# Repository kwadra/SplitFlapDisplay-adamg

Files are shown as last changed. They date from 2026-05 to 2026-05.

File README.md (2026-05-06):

# Split-Flap Display

A modular, 3D-printed split-flap display controllable over RS485 from a Raspberry Pi. Each module holds 64 characters and modules can be chained together to build a display of any width.

**YouTube Build Video:** https://www.youtube.com/watch?v=-C8_AtxEEQc

---

## How It Works

Each module contains:
- A 3D-printed drum that holds 64 individual flaps (one per character)
- A stepper motor driving the drum through a gear train
- A Hall effect sensor for homing
- A custom driver PCB (ATtiny1616 + RS485 transceiver + ULN2003 stepper driver)

Modules communicate over a shared RS485 bus. A Raspberry Pi running a Python web interface sends commands over USB-RS485 to each module individually by address.

---

## Repository Structure

```
cad/                       - 3D printable parts (Bambu Lab profiles included)
flaps-generator/           - OpenSCAD code to automatically generate (custom) flaps
pcb/
  driver-v2/               - Driver PCB KiCad project used in the video build
  driver-v3/               - Updated driver PCB KiCad project, slightly cheaper to manufacture
  bus-board/               - Bus board KiCad project
  bus-board-5-module/      - 5-module variant of the bus board
firmware/                  - Arduino firmware for the PCBs
frontend/                  - Raspberry Pi Python web frontend
docs/datasheets/           - Component datasheets
BOM.md                     - Bill of materials
```

**OnShape Model:** https://cad.onshape.com/documents/87c916b33ca5d6492b457485/w/b3e5f0f05f6619e6e7931347/e/582ef2164e20b0aa994708ab

---

## Parts List

See [BOM.md](BOM.md) for the complete bill of materials, broken into three sections:

- **PCB / Electronics** — all SMD components with JLCPCB part numbers for easy ordering
- **Module BOM** — 3D printed parts and hardware per module, with quantities scaled to 45 modules
- **Other Components** — system-level parts (Raspberry Pi, power supply, C14 connector, etc.)

---

## Ordering the PCB from JLCPCB

The driver board is designed to be ordered from JLCPCB with their PCB Assembly (PCBA) service so the SMD components arrive pre-soldered.

### Step 1 — Export Gerbers from KiCad

1. Open the project in `pcb/driver-v2/`
2. In KiCad PCB editor, go to **File → Fabrication Outputs → Gerbers**
3. Export to a folder, then zip the contents
4. Also export the drill file from the same menu

Alternatively, pre-exported Gerber and PCBA files are already be present in the KiCad project folder.

### Step 2 — Upload to JLCPCB

1. Go to [jlcpcb.com](https://jlcpcb.com) and click **Order Now**
2. Upload the Gerber zip file
3. Set your desired quantity (minimum 5)
4. Leave most settings at default; adjust PCB colour if desired

### Step 3 — Enable PCB Assembly (PCBA)

1. Toggle **PCB Assembly** on
2. Select **Standard PCBA** and set the assembly side to **Top Side**
3. Click **Confirm**

### Step 4 — Upload BOM and CPL Files

1. Upload the **BOM file** from the KiCad project folder — this maps component values to JLCPCB part numbers. The part numbers in `BOM.md` match what is in this file.
2. Upload the **CPL (Component Placement List)** file — this tells JLCPCB where each component sits on the board
3. Review the component matches on the next screen. All parts should auto-match using the C-numbers in [BOM.md](BOM.md). Confirm any that need manual review.

### Step 5 — Review and Order

1. Check the parts list — confirm quantities and part numbers match the [BOM.md](BOM.md) PCB section
2. Proceed through the review screens and place your order

> **Note:** A few through-hole parts (pin headers, JST connectors) are not included in PCBA. These are listed in the BOM and will need to be soldered by hand.

---

## 3D Printing

All printable files are in the `cad/` folder. A Bambu Lab print profile is included in `cad/64FlapsWithLetters (parts and bambu print profile)/` for the flaps. Print the flaps in the correct colour for each character — see the video for details on the full 64-character set.

Parts per module:
- Enclosure Body, Right Cover, Left Cover
- Drum Body, Drum Cap
- Motor Gear, Center Gear, Gear Plate
- DIN Rail Mount, Wire Retainer
- 64 Flaps

### Creating your own flaps

If you want to generate your own flaps, with your own font, size and characters, you can use the OpenSCAD script to automatically generate this.

---

## Firmware

Located in `firmware/`. The firmware is Arduino-based and targets the ATtiny1616.

- Flash via UPDI programmer (see https://github.com/SpenceKonde/AVR-Guidance/blob/master/UPDI/jtag2updi.md if you need to make one)
- Each module needs a unique address (0–44) stored in EEPROM. Be sure to edit this between flashes.

---

## Frontend

Located in `frontend/`. A Python web interface running on a Raspberry Pi sends display commands over USB-RS485 at 115200 baud.

Need a USB-serial dongle. I used this one: https://www.adafruit.com/product/5994

---

## License

This project is licensed under [Creative Commons Attribution-NonCommercial-ShareAlike 4.0 International (CC BY-NC-SA 4.0)](https://creativecommons.org/licenses/by-nc-sa/4.0/).

You are free to share and adapt this project for non-commercial purposes, as long as you give appropriate credit to Adam G Makes and distribute any derivatives under the same license.

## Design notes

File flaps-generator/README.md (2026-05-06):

# Flaps generator (`flaps.scad`)

## OpenSCAD (brief)

[OpenSCAD](https://openscad.org/) is a script-based 3D CAD tool: you describe models as code (extrusions, booleans, imports), adjust parameters, then preview or fully render solid geometry and export meshes (e.g. STL). There is no interactive mesh sculpting—changes are edits to the `.scad` file.

## What `flaps.scad` does

The script builds a grid of split-flap blanks matching the outline in `flap.dxf`. For each flap it uses **three adjacent characters** from your sequence (previous / visible / next) so the physical flap matches how letters wrap on a drum.

You control:

- **`font`** — font family and style (OpenSCAD font string, e.g. `Consolas:style=Regular`)
- **`fontsize`** — base letter height passed to OpenSCAD `text()` on each flap face
- **`chars`** — exactly **64 characters** in order; index `0…63` maps to the printed sheet (the loops stop before character index 64)
- **`charSizeOffset`** — Per character adjustment of the size. For example '@' can be make smaller.
- **`charYposOffset`** — Allows X position adjustment per character. The default is to align in the center. But characters like `'` need to be on the top

At the top of `flaps.scad`, `MakeFlaps(1)` produces the flap bodies with letter cutouts; `MakeFlaps(2)` produces only the thin letter inlays for multi-material printing.

## How to use

1. Set **`font`**, **`fontsize`**, **`chars`** (64 characters), and optionally **`charSizeOffset`** / **`charYposOffset`** (each 64 entries, aligned by index with **`chars`**) as needed.
2. **Flap bodies:** Comment out `MakeFlaps(2);` and keep **`MakeFlaps(1);`** active. Run a **full render** (OpenSCAD: **F6**), then **Export → Export as STL**.
3. **Letter inlays:** Comment out `MakeFlaps(1);` and keep **`MakeFlaps(2);`** active. Full render again (**F6**), export a second STL.

   *(Preview-only **F5** is not enough for a clean STL export; always use full render for exports.)*

4. **Bambu Studio:** Import **both** STL files. When prompted, choose **import as a single object** (so both parts stay aligned as one assembly).
5. In the object/plate list, assign **Filament 1** and **Filament 2** to the two bodies so the slicer maps each STL to the correct filament.

Example in Bambu Studio (Preview): one grouped object with body + inlay STLs, each mapped to a filament slot.

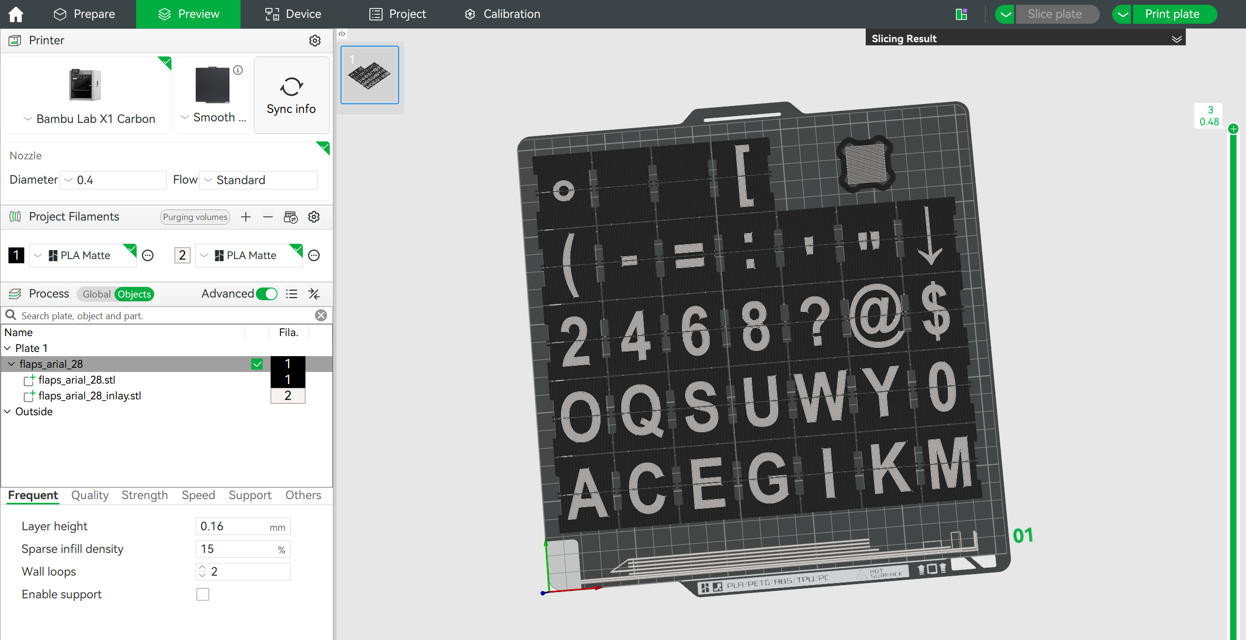
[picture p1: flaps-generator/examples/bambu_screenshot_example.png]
Bambu Studio: grouped flap body and inlay STLs with Filament 1 / Filament 2


License for this generator: see comments in `flaps.scad` (Creative Commons BY-NC-SA 4.0).

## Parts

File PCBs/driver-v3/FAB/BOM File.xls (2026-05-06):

Comment | Designator | Footprint | JLCPCB Part #
ATtiny1616-MNR | U1 | VQFN-20-1EP_3x3mm_P0.4mm_EP1.7x1.7mm | C507118
470n | C3,C8,C6,C2 | C_0603_1608Metric | C1623
ULN2003ADR | U2 | SOIC-16W_5.3x10.2mm_P1.27mm | C7512
HallEffect | J4 | PinHeader_1x03_P2.54mm_Vertical | C131339
100u | C1 | C_Elec_5x5.4 | C3347
100n | C7 | C_0603_1608Metric | C14663
0R | R1 | R_0805_2012Metric | C17477
LED | D1 | LED_0201_0603Metric | C2286
StepperConnector | J3 | JST_XH_B5B-XH-A_1x05_P2.50mm_Vertical | C157991
SN65HVD72DR | U3 | SOIC-8_5.3x6.2mm_P1.27mm | C48125
60R | R2 | R_0201_0603Metric | C166918
SPX3819M5-L-3-3 | U5 | SOT-23-5 | C20617301
SPX3819M5-L-5-0 | U6 | SOT-23-5 | C20617302
10u | C5,C9,C4 | C_0603_1608Metric | C19702

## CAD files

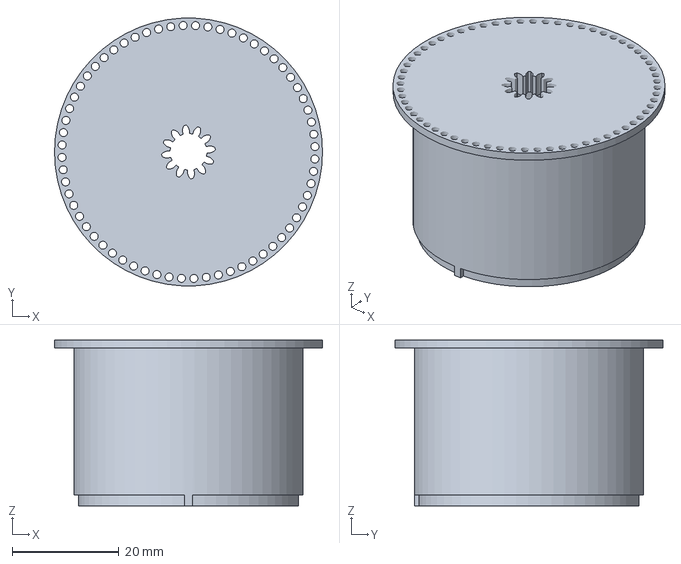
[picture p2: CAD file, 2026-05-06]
CAD Files/Character Drum - Character Drum Main.3mf
50.3 x 50.2 x 31.1 mm

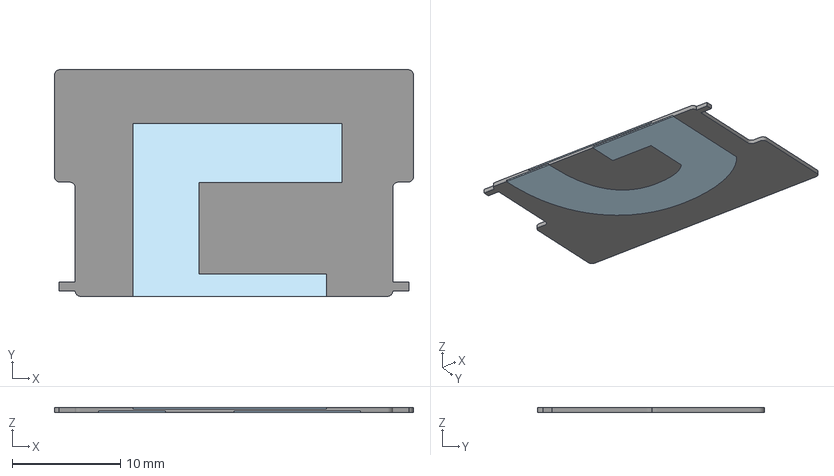
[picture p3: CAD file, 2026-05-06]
CAD Files/64FlapsWithLetters (parts and bambu print profile)/Flap7.3mf
33.1 x 20.9 x 0.48 mm
G_Bottom
Flap7
F_Top

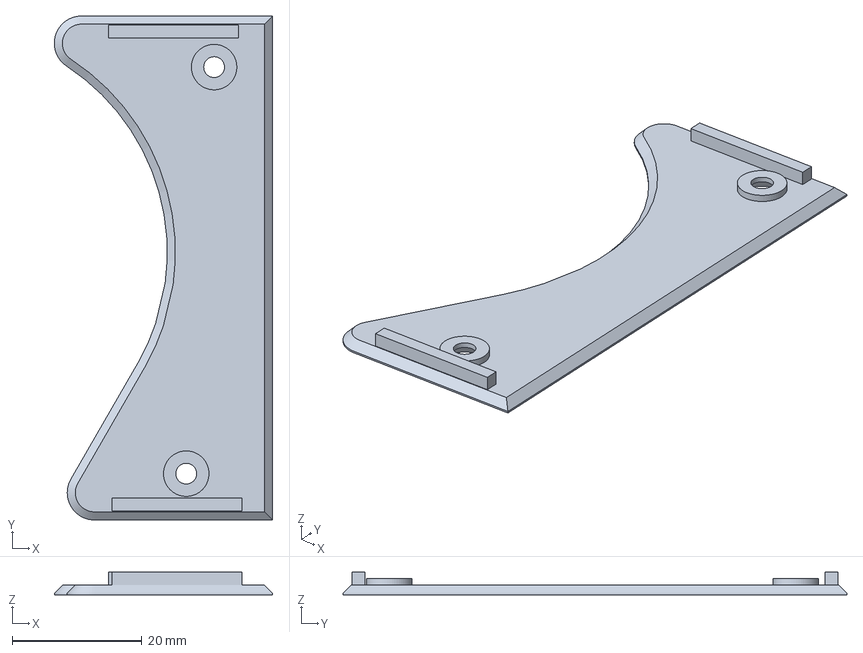
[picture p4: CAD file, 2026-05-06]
CAD Files/Module Enclosure - Enclosure Cover Bottom.3mf
33.6 x 77.6 x 3.50 mm

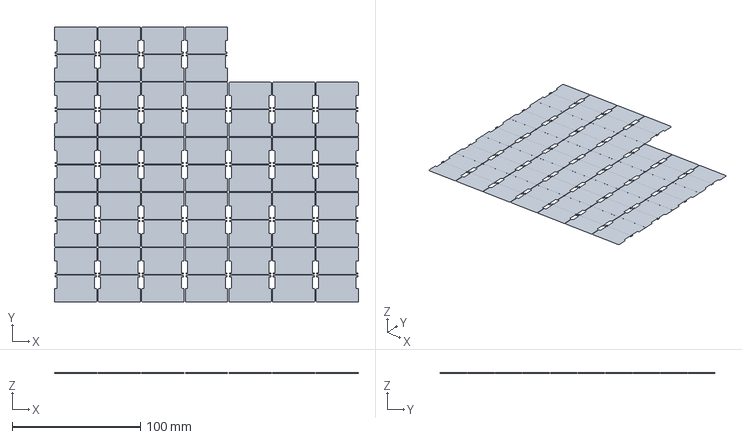
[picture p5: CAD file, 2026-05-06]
flaps-generator/examples/flaps_arial_28.3mf
237.1 x 214.3 x 0.48 mm

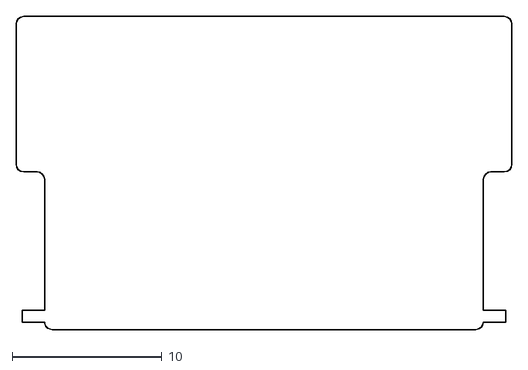
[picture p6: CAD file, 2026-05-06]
flaps-generator/flap.dxf
33.1 x 20.9

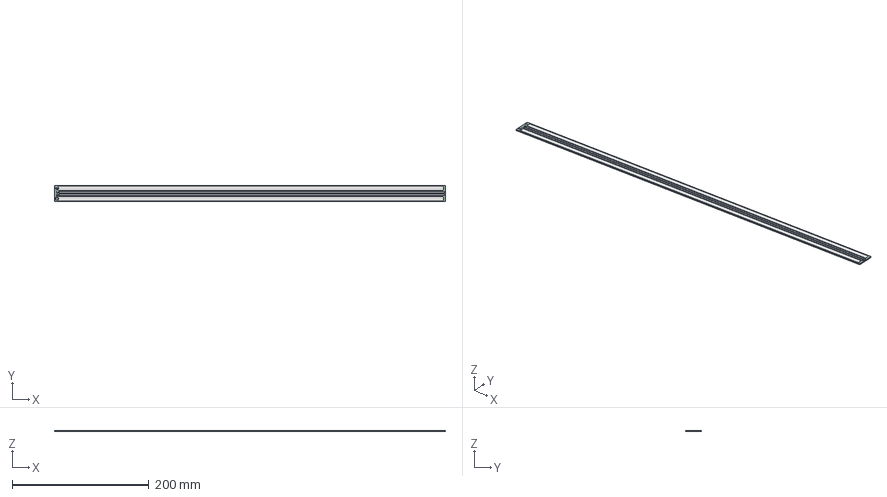
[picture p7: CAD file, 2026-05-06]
PCBs/bus-board/SplitFlapBusBoard.step
572.6 x 24.0 x 1.62 mm
SplitFlapBusBoard_pad
SplitFlapBusBoard_silkscreen
SplitFlapBusBoard_PCB

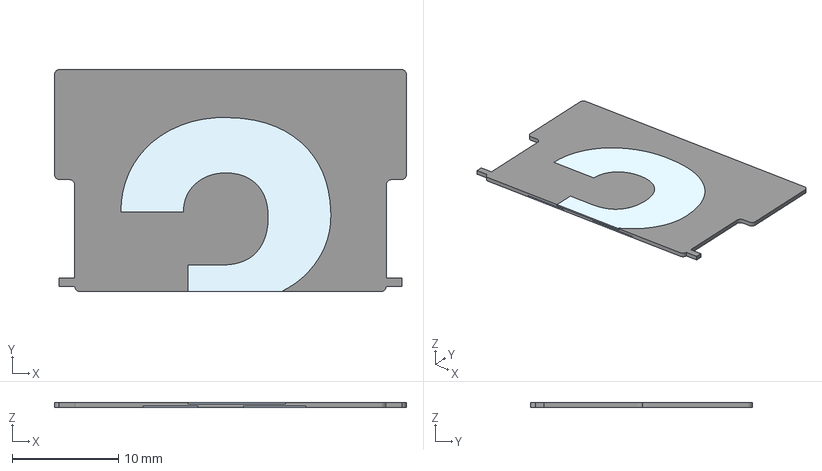
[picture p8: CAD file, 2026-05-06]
CAD Files/64FlapsWithLetters (parts and bambu print profile)/Flap31.3mf
33.1 x 20.9 x 0.48 mm
4_Bottom
Flap31
3_Top

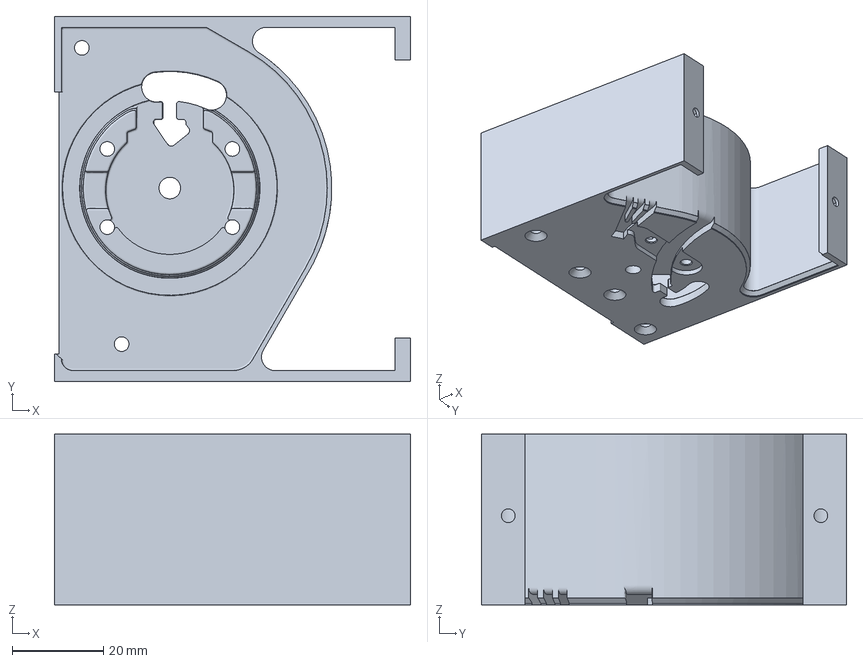
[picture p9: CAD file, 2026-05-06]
CAD Files/Module Enclosure - Enclosure.3mf
78.0 x 80.0 x 37.4 mm

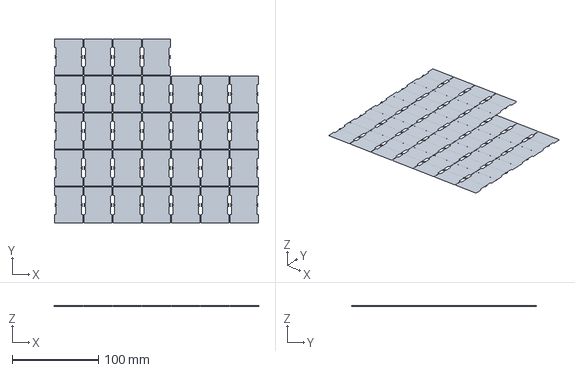
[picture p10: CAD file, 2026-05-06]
flaps-generator/examples/flaps_consolas_28.3mf
237.1 x 214.3 x 0.48 mm

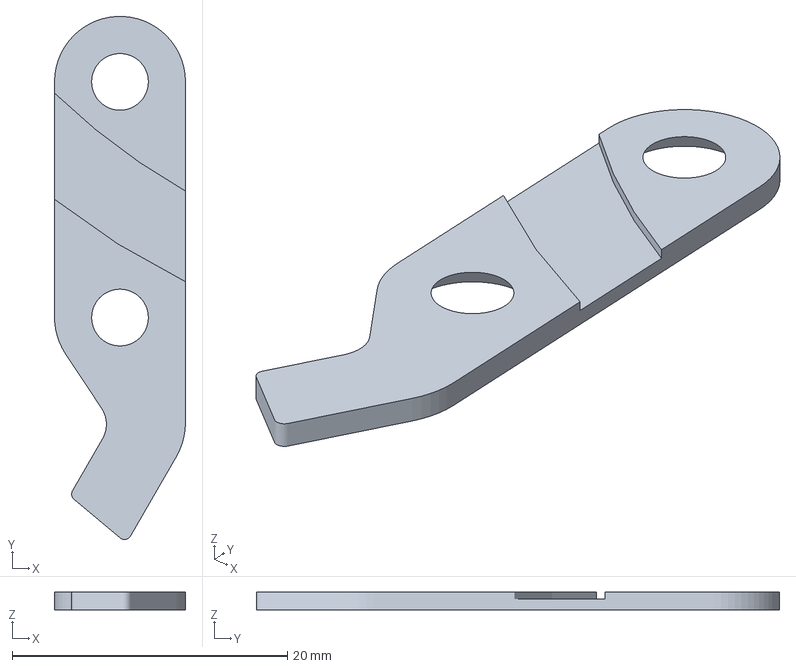
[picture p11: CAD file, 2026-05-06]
CAD Files/Wire Retainer.3mf
9.52 x 38.0 x 1.30 mm

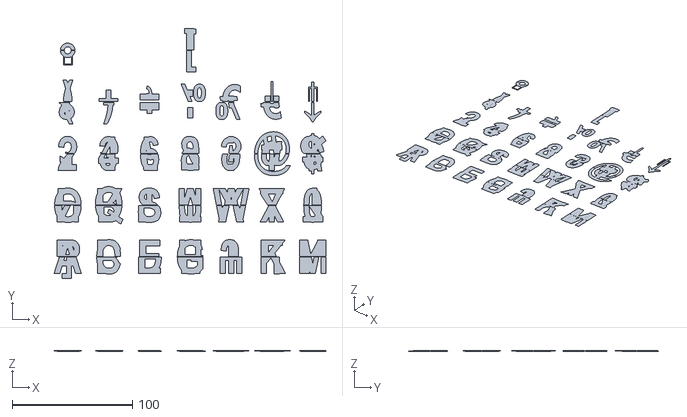
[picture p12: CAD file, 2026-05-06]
flaps-generator/examples/flaps_arial_28_inlay.stl
226.5 x 207.9 x 0.48

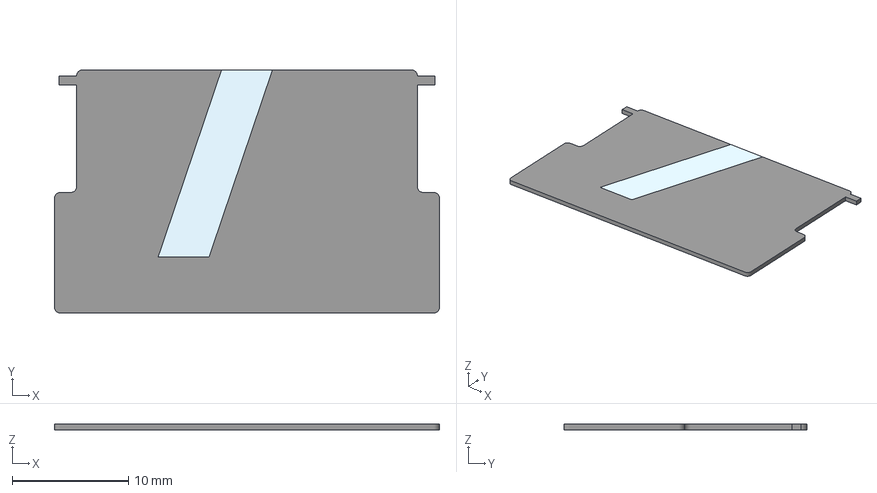
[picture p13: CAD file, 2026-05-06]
CAD Files/64FlapsWithLetters (parts and bambu print profile)/Flap54.3mf
33.1 x 20.9 x 0.48 mm
Flap54
Slash_Bottom

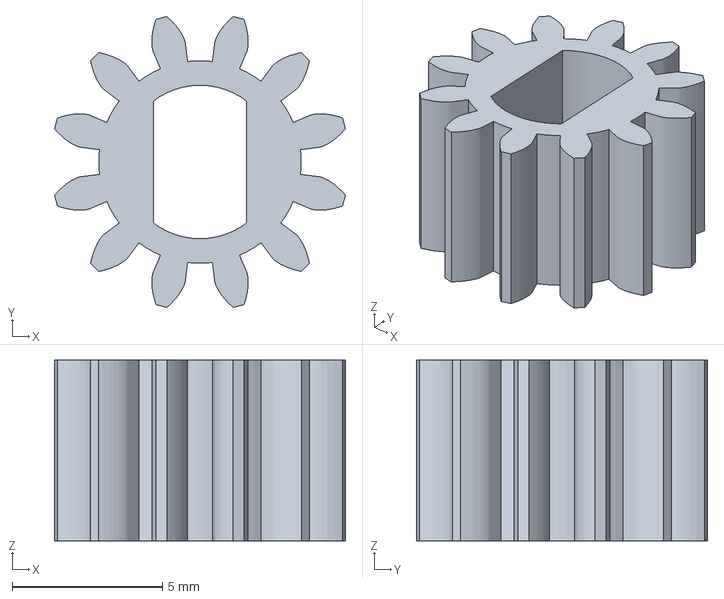
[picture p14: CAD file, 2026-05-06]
CAD Files/Motor Gear.3mf
9.67 x 9.67 x 6.00 mm

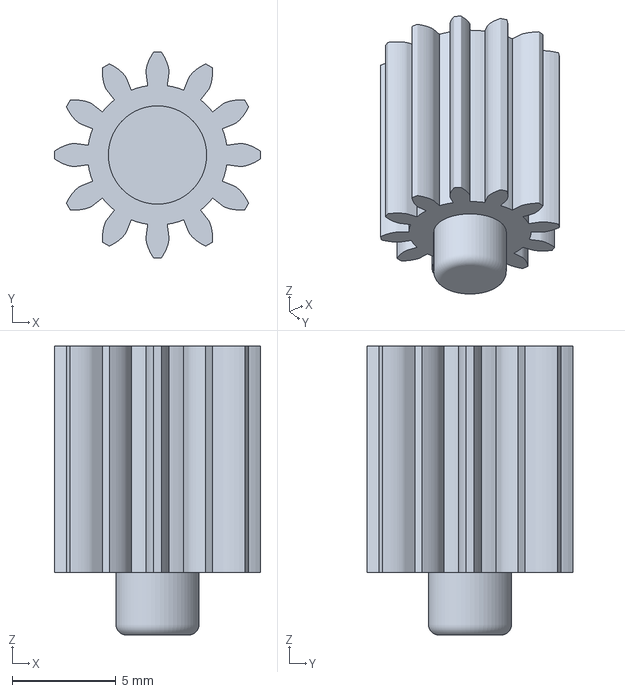
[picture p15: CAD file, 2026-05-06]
CAD Files/Center Gear.3mf
9.91 x 9.91 x 13.9 mm

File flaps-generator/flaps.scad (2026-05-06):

// Flap Generator for splitflap design based on: https://github.com/adamgmakes/SplitFlapDisplay
//
// Flap generator created by Richard Garsthagen (the.anykey@gmail.com)
// License under creative commons: https://creativecommons.org/licenses/by-nc-sa/4.0/

$fn=180; // Quality of render
layers = 3;
layerheight = 0.16;
font = "Consolas:style=bold";
fontsize = 28;

chars = "ABCDEFGHIJKLMNOPQRSTUVWXYZ0123456789?!@#$&()-+=;:%'\u20AC\"\u2191\u2193\u20BF\u00b0\u263A_   []";
charSizeOffset = [0,0,0,0,0,0,0,0,0,0,0,0,0,0,0,0,0,0,0,0,0,0,0,0,0,0,0,0,0,0,0,0,0,0,0,0,0,0,-4,0,0,0,0,0,0,0,0,0,0,0,0,0,0,0,0,0,0,0,0,0,0,0,0,0];
charYposOffset = [0,0,0,0,0,0,0,0,0,0,0,0,0,0,0,0,0,0,0,0,0,0,0,0,0,0,0,0,0,0,0,0,0,0,0,0,0,0,0,0,0,0,0,0,0,0,0,0,0,0,9,0,9,0,0,0,9,0,-12,0,0,0,0,0];


// Make the flaps 
MakeFlaps(1);

// Make the letter inlays
MakeFlaps(2);

module MakeFlaps(part){
    for ( y = [0 : 5] ){
        for ( x = [0 : 2 : 12] ){
            char = (y*14)+x;
            if (char<64) {
                if (char==0){
                 translate([17+(x*17),22+(y*43),0])
                 flap(63, char, char+1, part); }
                else if (char==63) {
                 translate([17+(x*17),22+(y*43),0])
                 flap(char-1, char, 0, part); }
                else {
                 translate([17+(x*17),22+(y*43),0])
                 flap(char-1, char, char+1, part);} 
            }
        }
    }
}

module flap(c1,c2,c3, part){
    //print flaps with character cutout
    if (part==1){
     difference(){ 
     union(){
     color("black")
     linear_extrude(h=(layers*layerheight))
     import("flap.dxf");
     
     color("black")
     linear_extrude(h=(layers*layerheight))
     rotate([0,0,180])
     import("flap.dxf");
     }
     char1(c1);
     char2(c2);
     char3(c3);
     }
    }

    //print just the characters
    if (part==2){
     char1(c1);
     char2(c2);
     char3(c3);
    }
}

module char1(c){
 difference(){
     color("white")
     translate([0,-charYposOffset[c],0])
     linear_extrude(h=layerheight)
     rotate([180,0,0])
     text(chars[c], size=fontsize+charSizeOffset[c], font=font, halign="center", valign="center");
     
     translate([-20,-0.25,0])
     cube([50,20,layerheight]);
 }
}

module char2(c){
difference(){
     color("white")
     translate([0,charYposOffset[c],layerheight*(layers-1)])
     linear_extrude(h=layerheight)
     text(chars[c], size=fontsize+charSizeOffset[c], font=font, halign="center", valign="center");
     
     translate([-20,-0.25,layerheight*(layers-1)])
     cube([50,0.5,layerheight]);
     
}
}

module char3(c){
 difference(){
     color("white")
     translate([0,-charYposOffset[c],0])
     linear_extrude(h=layerheight)
     rotate([180,0,0])
     text(chars[c], size=fontsize+charSizeOffset[c], font=font, halign="center", valign="center");
     
     translate([-20,-20+0.25,0])
     cube([50,20,layerheight]);
 }
}

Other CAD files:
CAD Files/64FlapsWithLetters (parts and bambu print profile)/Flap12.3mf
CAD Files/64FlapsWithLetters (parts and bambu print profile)/Flap2.3mf
CAD Files/64FlapsWithLetters (parts and bambu print profile)/Flap17.3mf
CAD Files/64FlapsWithLetters (parts and bambu print profile)/Flap26.3mf
CAD Files/64FlapsWithLetters (parts and bambu print profile)/64FlapsPrintProfile.3mf
CAD Files/64FlapsWithLetters (parts and bambu print profile)/Flap1.3mf
CAD Files/64FlapsWithLetters (parts and bambu print profile)/Flap10.3mf
CAD Files/64FlapsWithLetters (parts and bambu print profile)/Flap11.3mf
CAD Files/64FlapsWithLetters (parts and bambu print profile)/Flap13.3mf
CAD Files/64FlapsWithLetters (parts and bambu print profile)/Flap14.3mf
CAD Files/64FlapsWithLetters (parts and bambu print profile)/Flap15.3mf
CAD Files/64FlapsWithLetters (parts and bambu print profile)/Flap16.3mf
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

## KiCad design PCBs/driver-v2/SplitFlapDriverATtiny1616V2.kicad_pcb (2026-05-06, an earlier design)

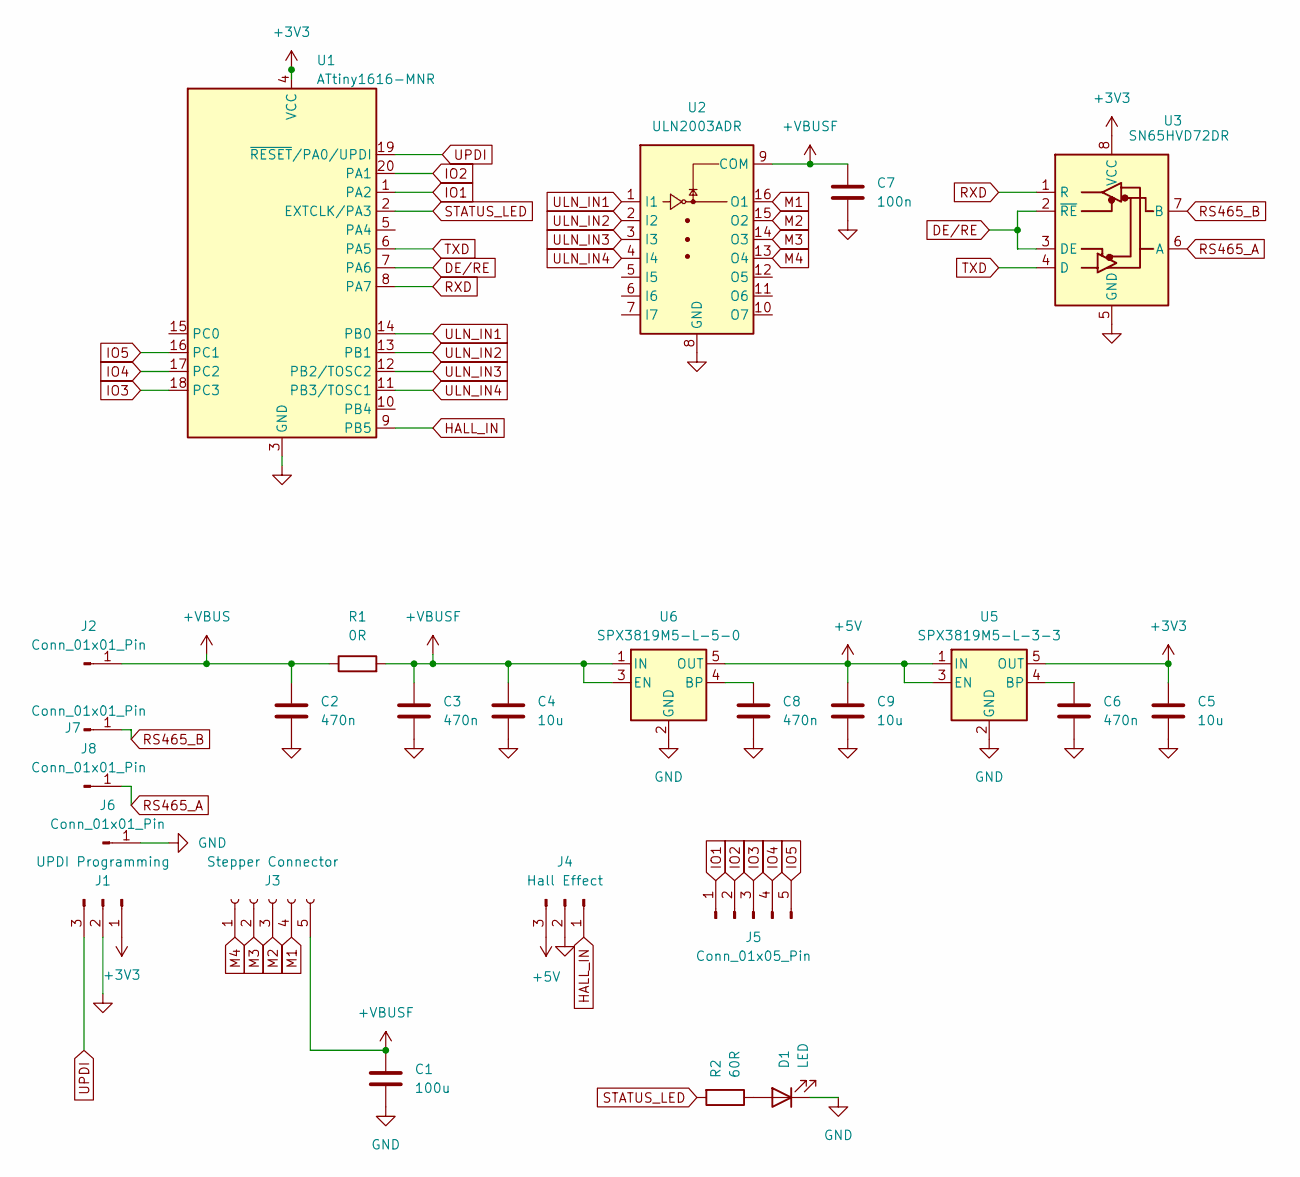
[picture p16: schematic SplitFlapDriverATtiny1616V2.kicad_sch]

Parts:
C1: 100u; C_Elec_5x5.4
C2, C3, C6, C8: 470n; C_0603_1608Metric
C4, C5, C9: 10u; C_0603_1608Metric
C7: 100n; C_0603_1608Metric
D1: LED; LED_0201_0603Metric
J1: UPDI Programming; PinHeader_1x03_P2.54mm_Vertical
J2, J6, J7, J8: Conn_01x01_Pin; PinHeader_1x01_P2.54mm_Vertical
J3: Stepper Connector; JST_XH_B5B-XH-A_1x05_P2.50mm_Vertical
J4: Hall Effect; JST_PH_B3B-PH-K_1x03_P2.00mm_Vertical
J5: Conn_01x05_Pin; PinHeader_1x05_P2.54mm_Vertical
R1: 0R; R_0805_2012Metric
R2: 60R; R_0201_0603Metric
U1: ATtiny1616-MNR; VQFN-20-1EP_3x3mm_P0.4mm_EP1.7x1.7mm; Manufacturer Part Number ATTINY1616-MNR; JLCPCB Part Number C507118
U2: ULN2003ADR; SOIC-16W_5.3x10.2mm_P1.27mm; Manufacturer Part Number ULN2003ADR; JLCPCB Part Number C7512
U3: SN65HVD72DR; SOIC-8_5.3x6.2mm_P1.27mm; Manufacturer Part Number SN65HVD72DR; JLCPCB Part Number C48125
U5: SPX3819M5-L-3-3; SOT-23-5
U6: SPX3819M5-L-5-0; SOT-23-5

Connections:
+3V3: C5.1, J1.1, U1.4 (VCC), U3.8 (VCC), U5.5 (OUT)
+5V: C9.1, J4.3, U5.1 (IN), U5.3 (EN), U6.5 (OUT)
+VBUS: C2.1, J2.1, R1.1
+VBUSF: C1.1, C3.1, C4.1, C7.1, J3.5, R1.2, U2.9 (COM), U6.1 (IN), U6.3 (EN)
DE/RE: U1.7 (PA6), U3.2 (~RE), U3.3 (DE)
GND: C1.2, C2.2, C3.2, C4.2, C5.2, C6.2, C7.2, C8.2, C9.2, D1.1 (K), J1.2, J4.2, J6.1, U1.3 (GND), U2.8 (GND), U3.5 (GND), U5.2 (GND), U6.2 (GND)
HALL_IN: J4.1, U1.9 (PB5)
IO1: J5.1, U1.1 (PA2)
IO2: J5.2, U1.20 (PA1)
IO3: J5.3, U1.18 (PC3)
IO4: J5.4, U1.17 (PC2)
IO5: J5.5, U1.16 (PC1)
M1: J3.4, U2.16 (O1)
M2: J3.3, U2.15 (O2)
M3: J3.2, U2.14 (O3)
M4: J3.1, U2.13 (O4)
unnamed: D1.2 (A), R2.1
unnamed: C6.1, U5.4 (BP)
unnamed: C8.1, U6.4 (BP)
RS465_A: J8.1, U3.6 (A)
RS465_B: J7.1, U3.7 (B)
RXD: U1.8 (PA7), U3.1 (R)
STATUS_LED: R2.2, U1.2 (EXTCLK/PA3)
TXD: U1.6 (PA5), U3.4 (D)
ULN_IN1: U1.14 (PB0), U2.1 (I1)
ULN_IN2: U1.13 (PB1), U2.2 (I2)
ULN_IN3: U1.12 (PB2/TOSC2), U2.3 (I3)
ULN_IN4: U1.11 (PB3/TOSC1), U2.4 (I4)
UPDI: J1.3, U1.19 (~RESET/PA0/UPDI)

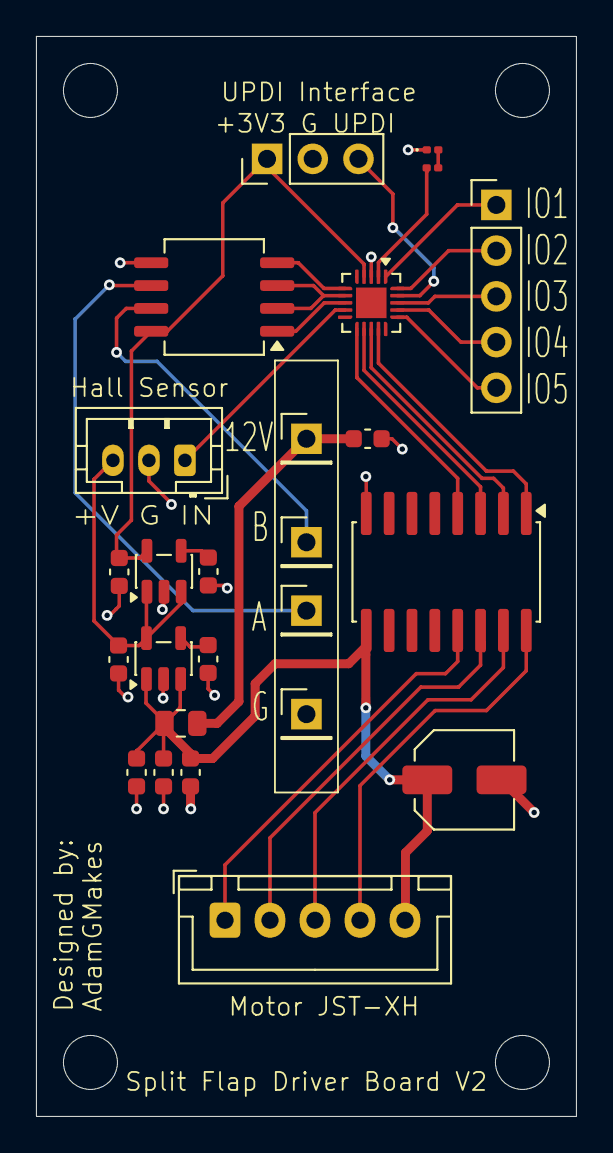
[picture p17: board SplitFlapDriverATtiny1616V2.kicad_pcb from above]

Board: 2 copper layers, 30.0 x 60.0 mm, 25 parts (0 on the bottom side), 29 nets.

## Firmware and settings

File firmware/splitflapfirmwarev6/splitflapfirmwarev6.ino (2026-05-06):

#include <SoftwareSerial.h>
#include <EEPROM.h>

// ==========================================
//               CONFIGURATION
// ==========================================
// !!! CHANGE THIS FOR EACH MODULE TODAY !!!
const uint8_t HARDCODED_ID = 38; 

const String FLAP_CHARS = " ABCDEFGHIJKLMNOPQRSTUVWXYZ0123456789!@#$&()-+=;q:%'.,/?*roygbpw";

// EEPROM MAP
const int ADDR_INIT = 0;          // 1 byte  - Initialization flag
const int ADDR_HOME_OFFSET = 1;   // 2 bytes - Offset from magnet
const int ADDR_TOTAL_STEPS = 3;   // 2 bytes - Step length of reel
const int ADDR_MODULE_ID = 5;     // 1 byte  - The Module's Assigned ID (0-44)
const int ADDR_AUTO_HOME = 6;     // 1 byte  - Toggle for booting logic
const int ADDR_SAVED_POS = 7;     // 2 bytes - Last known step position
const int ADDR_SAVED_INDEX = 9;   // 1 byte  - Last known character index
const int ADDR_MAP_START = 12;    // 128 bytes - Exact character positions
const uint8_t INIT_VALUE = 0x5D;  // Magic number updated for new map

// Operating Variables
uint8_t moduleId = 255;
char idChars[2] = {'*', '*'};
bool autoHomeEnabled = true;

int stepsFromHallToZero = 2832;
int totalStepsPerRev = 4096;

// ==========================================
//              PIN DEFINITIONS
// ==========================================
const int RS485_RX = 3;
const int RS485_TX = 1;
const int RS485_DE = 2;

#define IN1 9
#define IN2 8
#define IN3 7
#define IN4 6
#define HALL_PIN 4

// ==========================================
//               GLOBALS
// ==========================================
SoftwareSerial rs485(RS485_RX, RS485_TX);

long currentStepPos = 0; 
int currentPhase = 0;
int parseState = 0; 
int currentFlapIndex = -1;
int tempIndex = -1;

const int stepDelay = 1;
String buffer = "";
unsigned long lastSerialTime = 0;

const uint8_t halfStepSequence[8][4] = {
  {1, 0, 0, 0}, {1, 1, 0, 0}, {0, 1, 0, 0}, {0, 1, 1, 0},
  {0, 0, 1, 0}, {0, 0, 1, 1}, {0, 0, 0, 1}, {1, 0, 0, 1}
};

// ==========================================
//             EEPROM FUNCTIONS
// ==========================================

void saveHomeOffset() { EEPROM.put(ADDR_HOME_OFFSET, stepsFromHallToZero); }
void saveTotalSteps() { EEPROM.put(ADDR_TOTAL_STEPS, totalStepsPerRev); }

void saveState() {
  if (!autoHomeEnabled) {
    EEPROM.put(ADDR_SAVED_POS, currentStepPos);
    EEPROM.put(ADDR_SAVED_INDEX, currentFlapIndex);
  }
}

void updateIdChars() {
  if(moduleId < 100) {
    idChars[0] = (moduleId / 10) + '0';
    idChars[1] = (moduleId % 10) + '0';
  }
}

void dumpEeprom() {
  // CRITICAL FIX: Give the Raspberry Pi's USB dongle 50ms to switch into listening mode
  delay(50); 
  digitalWrite(RS485_DE, HIGH);
  delay(10); 
  
  rs485.print("m");
  if(moduleId < 10) rs485.print("0");
  rs485.print(moduleId);
  rs485.print("d:");
  rs485.print(stepsFromHallToZero);
  rs485.print(":");
  rs485.print(totalStepsPerRev);
  rs485.print(":");
  
  bool first = true;
  for(int i=0; i<64; i++) {
    uint16_t pos = 0xFFFF;
    EEPROM.get(ADDR_MAP_START + (i * 2), pos);
    if(pos != 0xFFFF) {
      if(!first) rs485.print(",");
      rs485.print(i);
      rs485.print("=");
      rs485.print(pos);
      first = false;
    }
  }
  
  rs485.print("\n");
  delay(100); 
  digitalWrite(RS485_DE, LOW);
}

// ==========================================
//             MOTOR FUNCTIONS
// ==========================================

void applyStep(const uint8_t *step) {
  digitalWrite(IN1, step[0]);
  digitalWrite(IN2, step[1]);
  digitalWrite(IN3, step[2]); 
  digitalWrite(IN4, step[3]);
}

void stepBackward(int steps) {
  for (int k = 0; k < steps; k++) {
    bool hallNow = hallActive();
    static bool lastHallState = false;

    if (hallNow && !lastHallState) {
      currentStepPos = totalStepsPerRev - stepsFromHallToZero;
    }
    lastHallState = hallNow;

    currentPhase--;
    if (currentPhase < 0) {
      currentPhase = 7;
    }
    
    applyStep(halfStepSequence[currentPhase]);
    delay(stepDelay);
    
    currentStepPos++;
    if (currentStepPos >= totalStepsPerRev) {
      currentStepPos = 0;
    }
  }
}

void releaseMotor() {
  digitalWrite(IN1,0); digitalWrite(IN2,0); digitalWrite(IN3,0); digitalWrite(IN4,0);
}

bool hallActive() {
  return (digitalRead(HALL_PIN) == LOW);
}

// ==========================================
//             LOGIC FUNCTIONS
// ==========================================

void homeModule() {
  long safety = 0;
  while (!hallActive() && safety < (totalStepsPerRev + 500)) {
    stepBackward(1);
    safety++;
  }
  
  stepBackward(stepsFromHallToZero);
  currentStepPos = 0; 
  currentFlapIndex = 0;
  releaseMotor();
}

void calibrateModule() {
  long safety = 0;
  while (hallActive() && safety < 4000) {
    stepBackward(1);
    safety++;
    delay(5);
  }

  safety = 0;
  while (!hallActive() && safety < 5000) {
    stepBackward(1);
    safety++;
  }

  while (hallActive()) {
    stepBackward(1);
  }

  int measuredSteps = 0;
  while (!hallActive() && measuredSteps < 5000) {
    stepBackward(1);
    measuredSteps++;
  }

  while (hallActive()) {
    stepBackward(1);
    measuredSteps++;
  }

  // CRITICAL FIX: Wait for Pi to be ready
  delay(50);
  digitalWrite(RS485_DE, HIGH);
  delay(10); 
  
  rs485.print("m");
  if(moduleId < 100) {
    rs485.print(idChars[0]);
    rs485.print(idChars[1]);
  } else {
    rs485.print("XX");
  }
  rs485.print(":");
  rs485.print(measuredSteps);
  rs485.print("\n");
  
  delay(100); 
  digitalWrite(RS485_DE, LOW);
  
  totalStepsPerRev = measuredSteps;
  saveTotalSteps();
  homeModule();
  saveState();
}

void moveToChar(char targetChar) {
  int targetIndex = FLAP_CHARS.indexOf(targetChar);
  if (targetIndex == -1) return;
  if (currentFlapIndex == targetIndex) return; 
  
  if (currentFlapIndex == -1) {
    homeModule();
  }

  uint16_t mappedPos = 0xFFFF;
  EEPROM.get(ADDR_MAP_START + (targetIndex * 2), mappedPos);
  
  long targetStepPos;
  if (mappedPos != 0xFFFF) {
    targetStepPos = mappedPos;
  } else {
    targetStepPos = ((long)targetIndex * (long)totalStepsPerRev) / 64;
  }
  
  long stepsToMove = targetStepPos - currentStepPos;
  if (stepsToMove < 0) {
    stepsToMove += totalStepsPerRev;
  }
  
  while(stepsToMove > 0) {
    stepBackward(1);
    stepsToMove--;
  }

  releaseMotor();
  currentFlapIndex = targetIndex; 
  saveState(); 
}

// ==========================================
//              MAIN LOOP
// ==========================================

void setup() {
  pinMode(IN1, OUTPUT);
  pinMode(IN2, OUTPUT);
  pinMode(IN3, OUTPUT); 
  pinMode(IN4, OUTPUT);
  pinMode(HALL_PIN, INPUT_PULLUP);
  
  pinMode(RS485_DE, OUTPUT);
  digitalWrite(RS485_DE, LOW); 
  
  if (EEPROM.read(ADDR_INIT) == INIT_VALUE) {
    EEPROM.get(ADDR_HOME_OFFSET, stepsFromHallToZero);
    EEPROM.get(ADDR_TOTAL_STEPS, totalStepsPerRev);
    moduleId = EEPROM.read(ADDR_MODULE_ID);
    autoHomeEnabled = (EEPROM.read(ADDR_AUTO_HOME) == 1);
  } else {
    EEPROM.write(ADDR_INIT, INIT_VALUE);
    saveHomeOffset();
    saveTotalSteps();
    
    moduleId = HARDCODED_ID; 
    EEPROM.write(ADDR_MODULE_ID, moduleId);
    
    EEPROM.write(ADDR_AUTO_HOME, 1);
    autoHomeEnabled = true;
    
    for(int i=0; i<64; i++) {
      uint16_t empty = 0xFFFF;
      EEPROM.put(ADDR_MAP_START + (i*2), empty);
    }
  }

  updateIdChars();
  rs485.begin(9600);

  if (moduleId != 255) {
    delay(moduleId * 150); 
  }
  
  if (autoHomeEnabled) {
    homeModule();
    saveState();
  } else {
    EEPROM.get(ADDR_SAVED_POS, currentStepPos);
    if (currentStepPos >= totalStepsPerRev) currentStepPos = 0;
    currentFlapIndex = (int8_t)EEPROM.read(ADDR_SAVED_INDEX);
  }
}

void loop() {
  while (rs485.available()) {
    char c = rs485.read();
    lastSerialTime = millis();
    
    switch (parseState) {
      case 0: if (c == 'm') parseState = 1; break;
      case 1: if (c == idChars[0] || c == '*') parseState = 2; else parseState = 0; break;
      case 2: if (c == idChars[1] || c == '*') parseState = 3; else parseState = 0; break;
      
      case 3: 
        if (c == '-') parseState = 4;
        else if (c == 'h') { homeModule(); saveState(); parseState = 0; }
        else if (c == 'c') { calibrateModule(); parseState = 0; }
        else if (c == 'o') { buffer = ""; parseState = 5; }
        else if (c == 't') { buffer = ""; parseState = 6; }
        else if (c == 's') { buffer = ""; parseState = 7; } 
        else if (c == 'g') { buffer = ""; parseState = 8; } 
        else if (c == 'w') { buffer = ""; tempIndex = -1; parseState = 9; } 
        else if (c == 'i') { buffer = ""; parseState = 10; } 
        else if (c == 'a') { buffer = ""; parseState = 11; } 
        else if (c == 'd') { dumpEeprom(); parseState = 0; } 
        else if (c == 'e') { 
          for(int i=0; i<64; i++) {
            uint16_t empty = 0xFFFF;
            EEPROM.put(ADDR_MAP_START + (i*2), empty);
          }
          parseState = 0;
        } 
        else parseState = 0;
        break;
        
      case 4: moveToChar(c); parseState = 0; break;
      
      case 5: 
        if (isDigit(c)) buffer += c;
        else { 
          if (buffer.length()>0) {
            stepsFromHallToZero = buffer.toInt(); 
            saveHomeOffset();
          }
          parseState=0; 
        }
        break;
        
      case 6: 
        if (isDigit(c)) buffer += c;
        else { 
          if (buffer.length()>0) {
            totalStepsPerRev = buffer.toInt(); 
            saveTotalSteps();
          }
          parseState=0; 
        }
        break;
        
      case 7: 
        if (isDigit(c)) buffer += c;
        else { 
          if (buffer.length()>0) {
            int stepsToMove = buffer.toInt();
            stepBackward(stepsToMove);
            releaseMotor();
            stepsFromHallToZero += stepsToMove;
            saveHomeOffset();
          }
          parseState=0; 
        }
        break;
        
      case 8: 
        if (isDigit(c)) buffer += c;
        else {
          if (buffer.length() > 0) {
            long targetStep = buffer.toInt();
            long stepsToMove = targetStep - currentStepPos;
            if (stepsToMove < 0) stepsToMove += totalStepsPerRev;
            while(stepsToMove > 0) { stepBackward(1); stepsToMove--; }
            releaseMotor();
            currentFlapIndex = -2;
            saveState(); 
          }
          parseState = 0;
        }
        break;
        
      case 9: 
        if (c == ':') {
          tempIndex = buffer.toInt();
          buffer = "";
        } else if (isDigit(c)) {
          buffer += c;
        } else {
          if (buffer.length() > 0 && tempIndex != -1) {
            uint16_t pos = buffer.toInt();
            EEPROM.put(ADDR_MAP_START + (tempIndex * 2), pos);
          }
          parseState = 0;
        }
        break;

      case 10: 
        if (isDigit(c)) buffer += c;
        else {
          if (buffer.length() > 0) {
            moduleId = buffer.toInt();
            EEPROM.write(ADDR_MODULE_ID, moduleId);
            updateIdChars();
          }
          parseState = 0;
        }
        break;

      case 11: 
        if (isDigit(c)) buffer += c;
        else {
          if (buffer.length() > 0) {
            autoHomeEnabled = (buffer.toInt() == 1);
            EEPROM.write(ADDR_AUTO_HOME, autoHomeEnabled ? 1 : 0);
            saveState();
          }
          parseState = 0;
        }
        break;
    }
  }

  if ((parseState >= 5 && parseState <= 11) && (millis() - lastSerialTime > 50)) {
    if (buffer.length() > 0) {
      if (parseState == 5) { stepsFromHallToZero = buffer.toInt(); saveHomeOffset(); }
      if (parseState == 6) { totalStepsPerRev = buffer.toInt(); saveTotalSteps(); }
      if (parseState == 7) {
        int stepsToMove = buffer.toInt();
        stepBackward(stepsToMove);
        releaseMotor();
        stepsFromHallToZero += stepsToMove;
        saveHomeOffset();
      }
      if (parseState == 8) {
        long targetStep = buffer.toInt();
        long stepsToMove = targetStep - currentStepPos;
        if (stepsToMove < 0) stepsToMove += totalStepsPerRev;
        while(stepsToMove > 0) { stepBackward(1); stepsToMove--; }
        releaseMotor();
        currentFlapIndex = -2;
        saveState();
      }
      if (parseState == 9 && tempIndex != -1) {
        uint16_t pos = buffer.toInt();
        EEPROM.put(ADDR_MAP_START + (tempIndex * 2), pos);
      }
      if (parseState == 10) {
        moduleId = buffer.toInt();
        EEPROM.write(ADDR_MODULE_ID, moduleId);
        updateIdChars();
      }
      if (parseState == 11) {
        autoHomeEnabled = (buffer.toInt() == 1);
        EEPROM.write(ADDR_AUTO_HOME, autoHomeEnabled ? 1 : 0);
        saveState();
      }
    }
    parseState = 0;
  }
}

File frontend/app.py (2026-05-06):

import serial
import time
import threading
import json
import os
import logging
import random
import requests
import pytz
import yfinance as yf
from datetime import datetime
from flask import Flask, render_template, request, jsonify

SERIAL_PORT = '/dev/ttyUSB0'
BAUD_RATE = 9600
CONFIG_PATH = "/home/gordo/splitflap/settings.json"

app = Flask(__name__)
logging.basicConfig(level=logging.INFO, format='%(asctime)s - %(message)s')

serial_lock = threading.Lock()

try:
    ser = serial.Serial(SERIAL_PORT, BAUD_RATE, timeout=0.5)
except Exception as e:
    ser = None
    logging.error(f"Serial failed. Simulation Mode. Reason: {e}")

# --- GLOBAL STATE ---
FLAP_CHARS = " ABCDEFGHIJKLMNOPQRSTUVWXYZ0123456789!@#$&()-+=;q:%'.,/?*roygbpw"
current_indices = [-1] * 45
current_display_string = " " * 45
is_homed = False


# ============================================================
#  SETTINGS
# ============================================================

def load_settings():
    defaults = {
        "offsets":       {str(i): 2832 for i in range(45)},
        "calibrations":  {str(i): 4096 for i in range(45)},
        "tuned_chars":   {str(i): {} for i in range(45)},
        "zip_code":      "02118",
        "timezone":      "US/Eastern",
        "weather_api_key": "",
        "mbta_stop":     "place-bbsta",
        "mbta_route":    "Orange",
        "stocks_list":   "MSFT,GOOG,NVDA",
        "nhl_teams":     "BOS,DAL",
        "yt_channel_id": "UC2GJfspFn6o4liy6GaBFtHA",
        "yt_api_key":    "",
        "yt_video_id":   "",
        "auto_home":     True,
        "countdown_event":   "NEW YEAR",
        "countdown_target":  "2027-01-01T00:00:00",
        "world_clock_zones": "US/Eastern,US/Pacific,Europe/London",
        "crypto_list":   "bitcoin,ethereum,solana",
        "anim_style":    "ltr",
        "anim_speed":    "0.4",
        "anim_text":     "SPLIT  FLAP  DISPLAY",
        "saved_playlists": {},
        "livestream_interval": "25",
        "livestream_comments": "",
    }
    if os.path.exists(CONFIG_PATH):
        try:
            with open(CONFIG_PATH, 'r') as f:
                data = json.load(f)
                defaults.update(data)
                if "tuned_chars" not in defaults:
                    defaults["tuned_chars"] = {str(i): {} for i in range(45)}
                return defaults
        except:
            pass
    return defaults

def save_settings(data):
    with open(CONFIG_PATH, 'w') as f:
        json.dump(data, f, indent=4)

settings = load_settings()


# ============================================================
#  SERIAL HELPERS
# ============================================================

def send_raw(cmd):
    if not cmd.endswith('\n'):
        cmd += '\n'
    with serial_lock:
        if ser:
            ser.write(cmd.encode())
            ser.flush()
            time.sleep(0.02)

def sync_hardware_data(mod_id):
    if not ser:
        return False
    with serial_lock:
        ser.reset_input_buffer()
        ser.write(f"m{mod_id:02d}d\n".encode())
        ser.flush()
        start = time.time()
        buffer = ""
        target = f"m{mod_id:02d}d:"
        while time.time() - start < 5.0:
            if ser.in_waiting > 0:
                try:
                    chunk = ser.read(ser.in_waiting).decode('utf-8', errors='ignore')
                    buffer += chunk
                    if target in buffer and '\n' in buffer[buffer.find(target):]:
                        valid_part = buffer[buffer.find(target):].split('\n')[0]
                        data = valid_part.split('d:', 1)[1]
                        parts = data.split(':')
                        if len(parts) >= 2:
                            settings['offsets'][str(mod_id)] = int(parts[0])
                            settings['calibrations'][str(mod_id)] = int(parts[1])
                            settings['tuned_chars'][str(mod_id)] = {}
                            if len(parts) == 3 and parts[2]:
                                for p in parts[2].split(','):
                                    if '=' in p:
                                        idx, val = p.split('=')
                                        settings['tuned_chars'][str(mod_id)][idx] = int(val)
                            save_settings(settings)
                            return True
                except Exception as e:
                    logging.error(f"Parse error: {e}")
            time.sleep(0.05)
    return False


# ============================================================
#  ANIMATION ORDER GENERATORS
# ============================================================

def get_animation_order(style='ltr'):
    """Return a list of the 45 module indices in the requested send order."""
    def m(r, c): return r * 15 + c

    if style == 'rtl':
        return list(range(44, -1, -1))

    elif style == 'center_out':
        order, seen = [], set()
        for d in range(8):
            for r in range(3):
                cols = [7] if d == 0 else [7 - d, 7 + d]
                for c in cols:
                    if 0 <= c < 15:
                        idx = m(r, c)
                        if idx not in seen:
                            seen.add(idx); order.append(idx)
        return order

    elif style == 'outside_in':
        return list(reversed(get_animation_order('center_out')))

    elif style == 'spiral':
        vis = [[False] * 15 for _ in range(3)]
        order = []
        top, bottom, left, right = 0, 2, 0, 14
        while top <= bottom and left <= right:
            for c in range(left, right + 1):
                if not vis[top][c]:
                    vis[top][c] = True; order.append(m(top, c))
            for r in range(top + 1, bottom + 1):
                if not vis[r][right]:
                    vis[r][right] = True; order.append(m(r, right))
            if top < bottom:
                for c in range(right - 1, left - 1, -1):
                    if not vis[bottom][c]:
                        vis[bottom][c] = True; order.append(m(bottom, c))
            if left < right:
                for r in range(bottom - 1, top, -1):
                    if not vis[r][left]:
                        vis[r][left] = True; order.append(m(r, left))
            top += 1; bottom -= 1; left += 1; right -= 1
        return order

    elif style == 'diagonal':
        order, seen = [], set()
        for d in range(17):
            for r in range(3):
                c = d - r
                if 0 <= c < 15:
                    idx = m(r, c)
                    if idx not in seen:
                        seen.add(idx); order.append(idx)
        return order

    elif style == 'anti_diagonal':
        order, seen = [], set()
        for d in range(17):
            for r in range(3):
                c = (14 - d) + r
                if 0 <= c < 15:
                    idx = m(r, c)
                    if idx not in seen:
                        seen.add(idx); order.append(idx)
        return order
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
